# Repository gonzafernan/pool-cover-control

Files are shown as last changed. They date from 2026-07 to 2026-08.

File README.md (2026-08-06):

# Pool Cover Control Board

Electronic control board for an automatic residential pool cover. Drives a 24V DC brushed motor in both directions using a relay H-bridge, with inputs from a key switch and mechanical limit switches.

## Overview

The board replaces a failed original controller. It is designed for direct drop-in installation into the existing enclosure, preserving all external wiring and mechanical components.

## Hardware

- **MCU:** STM32G031K8T6 (ARM Cortex-M0+, 64MHz, no external crystal)
- **Motor control:** 4x SLA-24VDC-SL-C SPDT relays in H-bridge configuration, driven by ULN2003A
- **Power input:** 24V, 10A fused, from external 25A/600W PSU in the same enclosure
- **Logic supply:** 3.3V via LMR14206XMKE/NOPB synchronous buck converter
- **Inputs:** 3-position maintained key switch, two NC limit switches, isolated via PC817 optocouplers
- **Protection:** Reverse polarity (P-FET), motor TVS, relay hardware interlock, firmware watchdog
- **Manufacturer:** JLCPCB

## Firmware

- Toolchain: STM32CubeMX + Makefile + GCC
- State machine: IDLE / OPENING / CLOSING / FAULT
- Motor timeout: 60 seconds
- Internal IWDG watchdog enabled

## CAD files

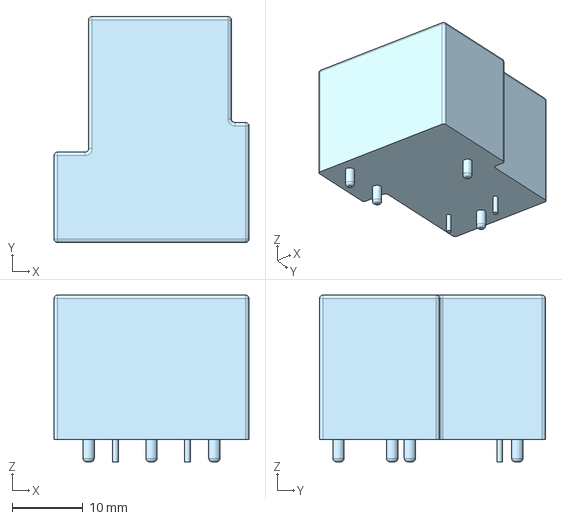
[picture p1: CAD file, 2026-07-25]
hardware/3d-models/SLA-24VDC-SL-C.step
27.6 x 32.0 x 23.6 mm

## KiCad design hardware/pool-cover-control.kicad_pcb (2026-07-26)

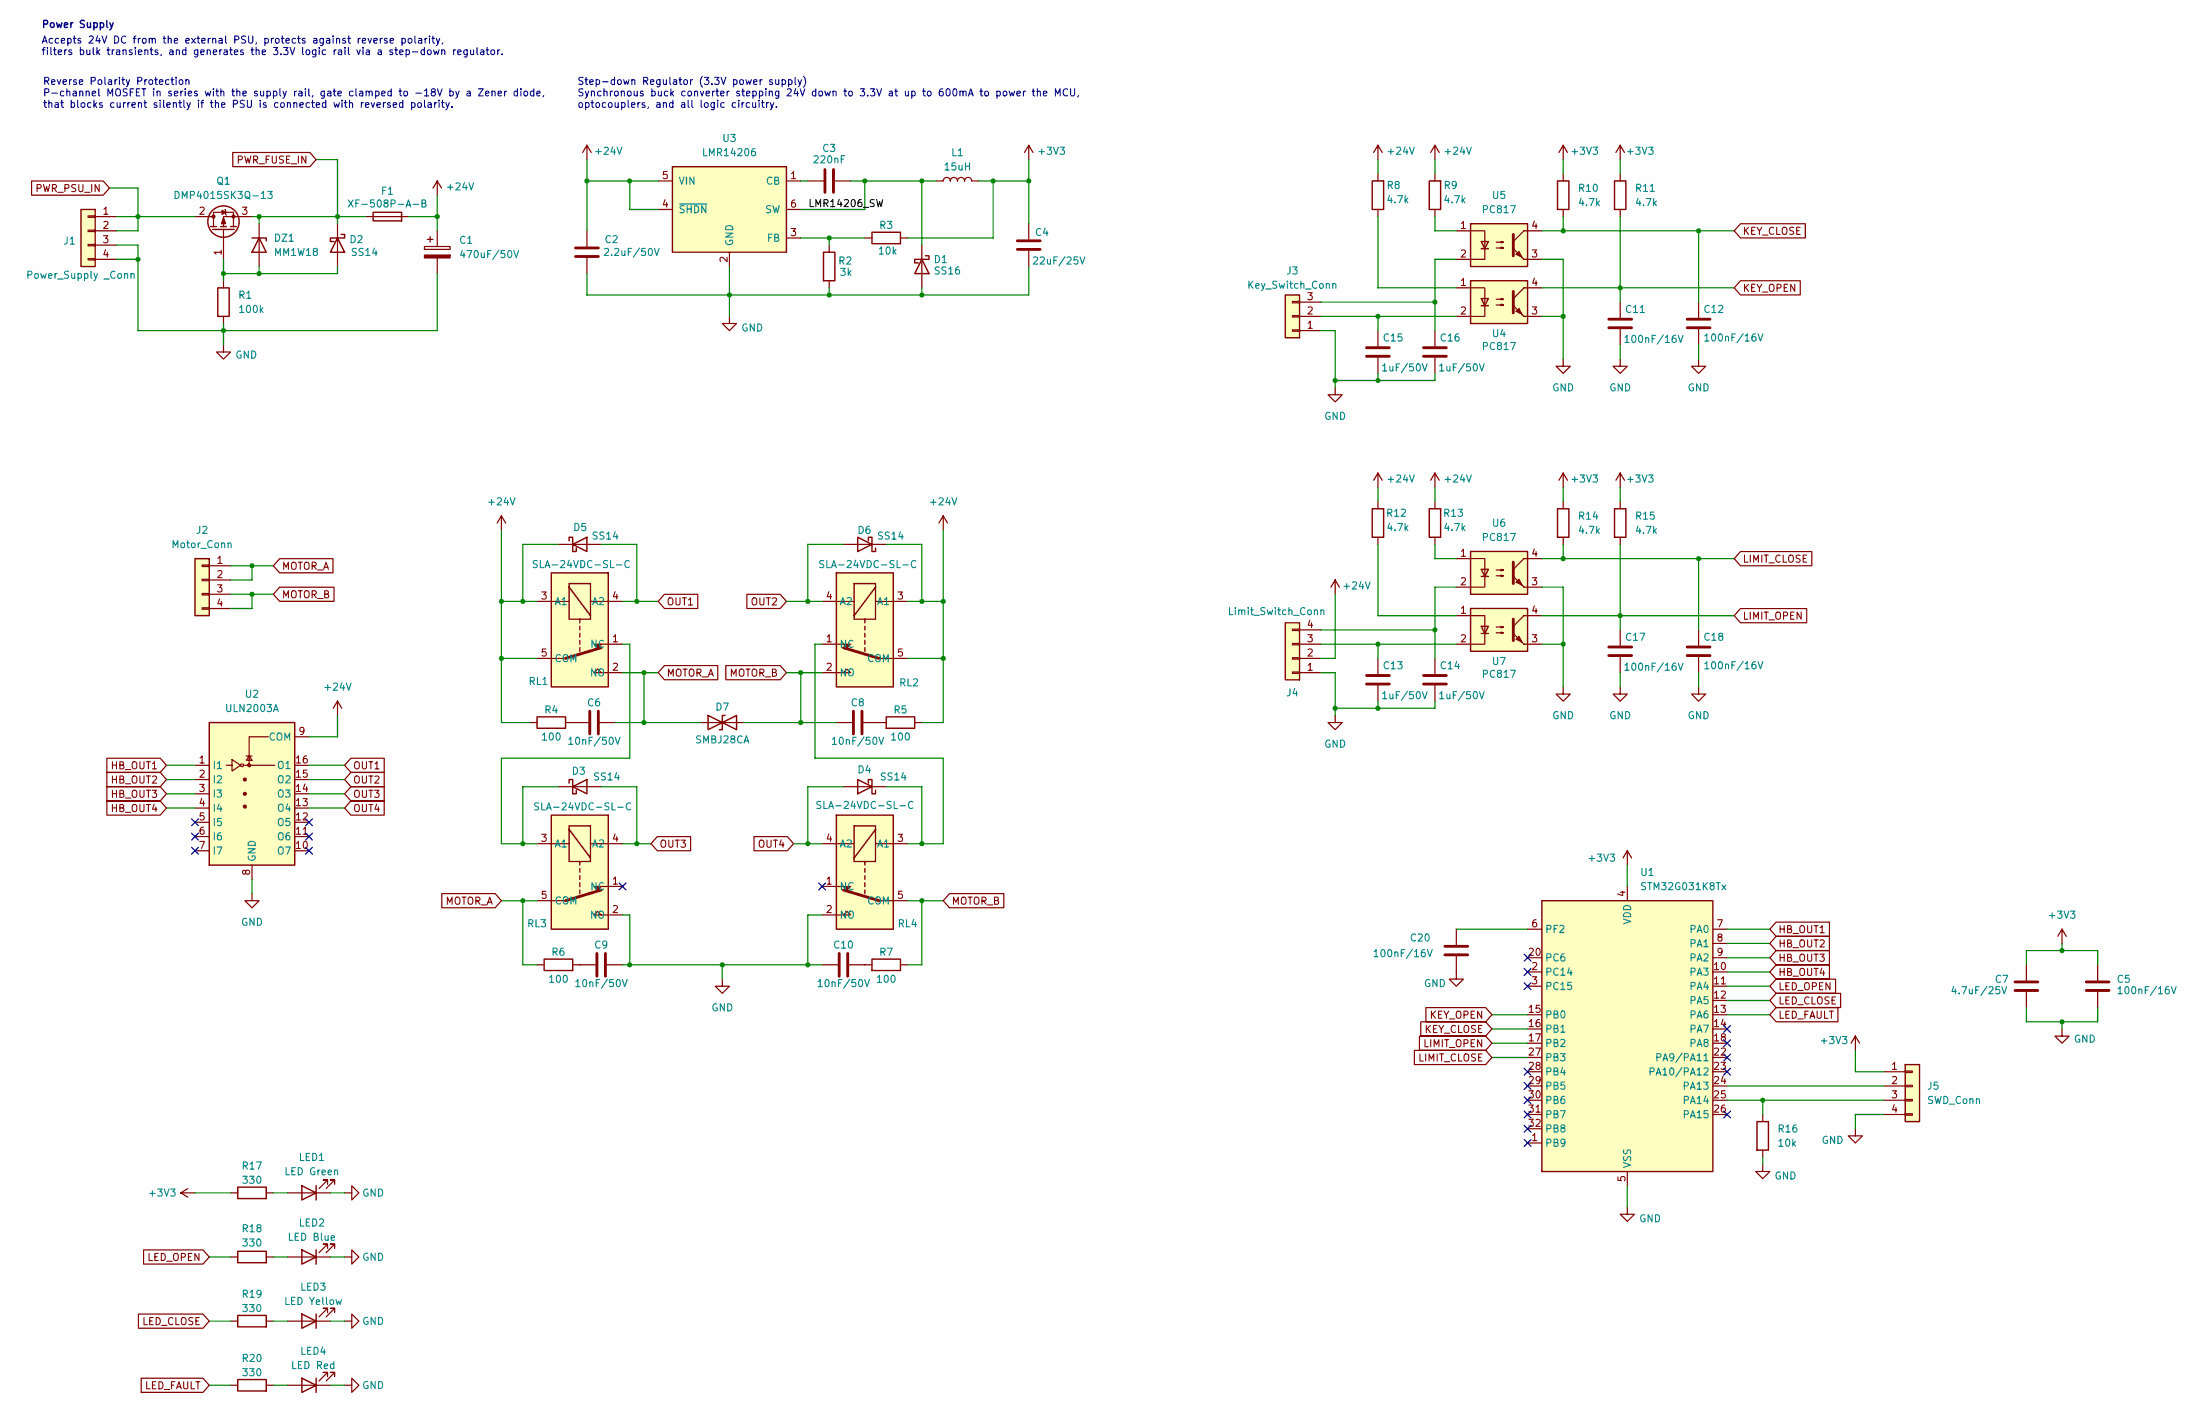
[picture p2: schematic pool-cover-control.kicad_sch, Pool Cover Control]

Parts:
C1: 470uF/50V; C_Radial_D10.0mm_H20.0mm_P5.00mm; LCSC C233099
C2: 2.2uF/50V; C_1206_3216Metric; LCSC 1206
C3: 220nF; C_0603_1608Metric; LCSC C21120
C4: 22uF/25V; C_1206_3216Metric; LCSC C12891
C5, C11, C12, C17, C18, C20: 100nF/16V; C_0402_1005Metric; LCSC C1525
C6, C8, C9, C10: 10nF/50V; C_0603_1608Metric; LCSC C57112
C7: 4.7uF/25V; C_0805_2012Metric; LCSC C1779
C13, C14, C15, C16: 1uF/50V; C_0603_1608Metric; LCSC C15849
D1: SS16; D_SMA; LCSC C908233
D2, D3, D4, D5, D6: SS14; D_SMA; LCSC C2480
D7: SMBJ28CA; D_SMB; LCSC C151259
DZ1: MM1W18; D_SOD-123; LCSC C382948
F1: XF-508P-A-B; Fuseholder_Blade_Mini_XFCN XF-508P-A-B; LCSC C19727304
J1: Power_Supply _Conn; TerminalBlock_Phoenix_MKDS-1,5-4-5.08_1x04_P5.08mm_Horizont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; LCSC C90087
J2: Motor_Conn; TerminalBlock_Phoenix_MKDS-1,5-4-5.08_1x04_P5.08mm_Horizont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; LCSC C90087
J3: Key_Switch_Conn; TerminalBlock_Phoenix_MKDS-1,5-3-5.08_1x03_P5.08mm_Horizont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; LCSC C91156
J4: Limit_Switch_Conn; TerminalBlock_Phoenix_MKDS-1,5-4-5.08_1x04_P5.08mm_Horizont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; LCSC C90087
J5: SWD_Conn; PinHeader_1x04_P2.54mm_Vertical; LCSC C2691448
L1: 15uH; L_Bourns_SRP7028A_7.3x6.6mm; LCSC C1847948
LED1: LED Green; LED_0603_1608Metric; LCSC C2286
LED2: LED Blue; LED_0603_1608Metric; LCSC C2286
LED3: LED Yellow; LED_0603_1608Metric; LCSC C2286
LED4: LED Red; LED_0603_1608Metric; LCSC C2286
Q1: DMP4015SK3Q-13; TO-252-3_TabPin2; LCSC C461089
R1: 100k; R_0402_1005Metric; LCSC C25741
R2: 3k; R_0603_1608Metric; LCSC C4211
R3, R16: 10k; R_0603_1608Metric; LCSC C25804
R4, R5, R6, R7: 100; R_0603_1608Metric; LCSC C22775
R8, R9, R12, R13: 4.7k; R_1206_3216Metric_Pad1.30x1.75mm_HandSolder; LCSC C17936
R10, R11, R14, R15: 4.7k; R_0402_1005Metric; LCSC C25900
R17, R18, R19, R20: 330; R_0402_1005Metric; LCSC C25104
RL1, RL2, RL3, RL4: SLA-24VDC-SL-C; SLA-XXVDC-SL-C; LCSC C187898
U1: STM32G031K8Tx; LQFP-32_7x7mm_P0.8mm; LCSC C724059
U2: ULN2003A; SOIC-16_3.9x9.9mm_P1.27mm; LCSC C7512
U3: LMR14206; SOT-23-6; LCSC C2071127
U4, U5, U6, U7: PC817; SOP-4_7.5x4.1mm_P2.54mm; LCSC C22447129

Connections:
+3V3: C4.2, C5.2, C7.2, J5.1, L1.2, R3.2, R10.1, R11.1, R14.1, R15.1, R17.1, U1.4 (VDD)
+24V: C1.1, C2.2, D5.1 (K), D6.1 (K), F1.2, J4.2, R4.1, R5.1, R8.2, R9.2, R12.2, R13.2, RL1.3 (A1), RL1.5 (COM), RL2.3 (A1), RL2.5 (COM), U2.9 (COM), U3.4 (~SHDN), U3.5 (VIN)
/LMR14206_SW: C3.2, D1.1 (K), L1.1, U3.6 (SW)
GND: C1.2, C2.1, C4.1, C5.1, C7.1, C9.2, C10.2, C11.1, C12.1, C13.1, C14.1, C15.1, C16.1, C17.1, C18.1, C20.1, D1.2 (A), J1.3, J1.4, J3.1, J4.1, J5.4, LED1.1 (K), LED2.1 (K), LED3.1 (K), LED4.1 (K), R1.2, R2.2, R16.2, RL3.2 (NO), RL4.2 (NO), U1.5 (VSS), U2.8 (GND), U3.2 (GND), U4.3, U5.3, U6.3, U7.3
HB_OUT1: U1.7 (PA0), U2.1 (I1)
HB_OUT2: U1.8 (PA1), U2.2 (I2)
HB_OUT3: U1.9 (PA2), U2.3 (I3)
HB_OUT4: U1.10 (PA3), U2.4 (I4)
KEY_CLOSE: C12.2, R10.2, U1.16 (PB1), U5.4
KEY_OPEN: C11.2, R11.2, U1.15 (PB0), U4.4
LED_CLOSE: R19.1, U1.12 (PA5)
LED_FAULT: R20.1, U1.13 (PA6)
LED_OPEN: R18.1, U1.11 (PA4)
LIMIT_CLOSE: C18.2, R14.2, U1.27 (PB3), U6.4
LIMIT_OPEN: C17.2, R15.2, U1.17 (PB2), U7.4
MOTOR_A: C6.2, D7.1 (A1), J2.1, J2.2, R6.1, RL1.2 (NO), RL3.5 (COM)
MOTOR_B: C8.2, D7.2 (A2), J2.3, J2.4, R7.1, RL2.2 (NO), RL4.5 (COM)
unnamed: C6.1, R4.2
unnamed: C8.1, R5.2
unnamed: C9.1, R6.2
unnamed: C10.1, R7.2
unnamed: D2.2 (A), DZ1.2 (A), Q1.1 (G), R1.1
unnamed: D3.1 (K), RL1.1 (NC), RL3.3 (A1)
unnamed: D4.1 (K), RL2.1 (NC), RL4.3 (A1)
unnamed: C15.2, J3.2, U4.2
unnamed: C16.2, J3.3, U5.2
unnamed: C13.2, J4.3, U7.2
unnamed: C14.2, J4.4, U6.2
unnamed: J5.2, U1.24 (PA13)
unnamed: J5.3, R16.1, U1.25 (PA14)
unnamed: LED1.2 (A), R17.2
unnamed: LED2.2 (A), R18.2
unnamed: LED3.2 (A), R19.2
unnamed: LED4.2 (A), R20.2
unnamed: R8.1, U4.1
unnamed: R9.1, U5.1
unnamed: R12.1, U7.1
unnamed: R13.1, U6.1
unnamed: C20.2, U1.6 (PF2)
unnamed: C3.1, U3.1 (CB)
unnamed: R2.1, R3.1, U3.3 (FB)
OUT1: D5.2 (A), RL1.4 (A2), U2.16 (O1)
OUT2: D6.2 (A), RL2.4 (A2), U2.15 (O2)
OUT3: D3.2 (A), RL3.4 (A2), U2.14 (O3)
OUT4: D4.2 (A), RL4.4 (A2), U2.13 (O4)
PWR_FUSE_IN: D2.1 (K), DZ1.1 (K), F1.1, Q1.3 (S)
PWR_PSU_IN: J1.1, J1.2, Q1.2 (D)

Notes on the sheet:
Reverse Polarity Protection P-channel MOSFET in series with the supply rail, gate clamped to −18V by a Zener diode, that blocks current silently if the PSU is connected with reversed polarity.
Power Supply
Accepts 24V DC from the external PSU, protects against reverse polarity, filters bulk transients, and generates the 3.3V logic rail via a step-down regulator.
Step-down Regulator (3.3V power supply) Synchronous buck converter stepping 24V down to 3.3V at up to 600mA to power the MCU, optocouplers, and all logic circuitry.

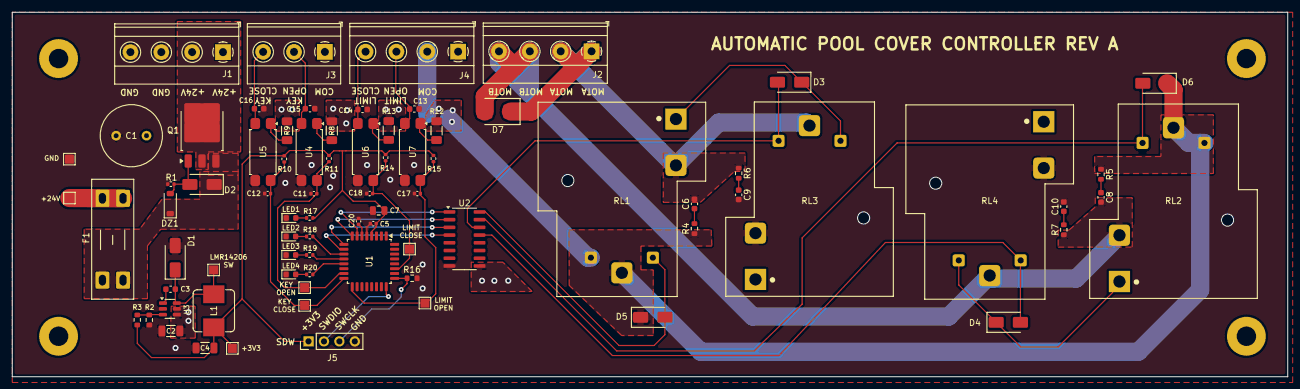
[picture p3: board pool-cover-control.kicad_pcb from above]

Board: 2 copper layers, 210.0 x 60.0 mm, 70 parts (0 on the bottom side), 47 nets.

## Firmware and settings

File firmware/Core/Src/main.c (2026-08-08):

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
/* Includes ------------------------------------------------------------------*/
#include "main.h"
#include "gpio.h"
#include "iwdg.h"

/* USER CODE BEGIN Includes */
#include "hbridge.h"
#include "key.h"
/* USER CODE END Includes */


void SystemClock_Config(void);
/**
 * @brief  The application entry point.
 * @retval int
 */
int main(void) {

  /* USER CODE BEGIN 1 */
  key_state_t key_state;
  /* USER CODE END 1 */

  /* MCU Configuration--------------------------------------------------------*/

  /* Reset of all peripherals, Initializes the Flash interface and the Systick.
   */
  HAL_Init();

  /* USER CODE BEGIN Init */
  __HAL_DBGMCU_FREEZE_IWDG();
  /* USER CODE END Init */

  /* Configure the system clock */
  SystemClock_Config();

  /* Initialize all configured peripherals */
  MX_GPIO_Init();
  MX_IWDG_Init();
  /* USER CODE BEGIN 2 */
  key_init(KEY_OPEN_GPIO_Port, KEY_OPEN_Pin, KEY_CLOSE_GPIO_Port,
           KEY_CLOSE_Pin);

  hbridge_init(HB_OUT1_GPIO_Port, HB_OUT1_Pin, HB_OUT2_GPIO_Port, HB_OUT2_Pin,
               HB_OUT3_GPIO_Port, HB_OUT3_Pin, HB_OUT4_GPIO_Port, HB_OUT4_Pin);
  /* USER CODE END 2 */

  /* Infinite loop */
  /* USER CODE BEGIN WHILE */
  while (1) {
    key_update();
    key_state = key_get_state();
    if (key_state == KEY_OPEN) {
      HAL_GPIO_WritePin(LED_OPEN_GPIO_Port, LED_OPEN_Pin, GPIO_PIN_SET);
      HAL_GPIO_WritePin(LED_CLOSE_GPIO_Port, LED_CLOSE_Pin, GPIO_PIN_RESET);
      HAL_GPIO_WritePin(LED_FAULT_GPIO_Port, LED_FAULT_Pin, GPIO_PIN_RESET);
      hbridge_set_state(HBRIDGE_POSITIVE);
    } else if (key_state == KEY_CLOSE) {
      HAL_GPIO_WritePin(LED_CLOSE_GPIO_Port, LED_CLOSE_Pin, GPIO_PIN_SET);
      HAL_GPIO_WritePin(LED_OPEN_GPIO_Port, LED_OPEN_Pin, GPIO_PIN_RESET);
      HAL_GPIO_WritePin(LED_FAULT_GPIO_Port, LED_FAULT_Pin, GPIO_PIN_RESET);
      hbridge_set_state(HBRIDGE_NEGATIVE);
    } else {
      HAL_GPIO_WritePin(LED_FAULT_GPIO_Port, LED_FAULT_Pin, GPIO_PIN_SET);
      HAL_GPIO_WritePin(LED_OPEN_GPIO_Port, LED_OPEN_Pin, GPIO_PIN_RESET);
      HAL_GPIO_WritePin(LED_CLOSE_GPIO_Port, LED_CLOSE_Pin, GPIO_PIN_RESET);
      hbridge_set_state(HBRIDGE_NONE);
    }
    HAL_IWDG_Refresh(&hiwdg);

    /* USER CODE END WHILE */

    /* USER CODE BEGIN 3 */
  }
  /* USER CODE END 3 */
}

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


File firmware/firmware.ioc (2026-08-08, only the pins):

Mcu.UserName=STM32G031K8Tx
PA0.GPIO_Label=HB_OUT1
PA0.Signal=GPIO_Output
PA1.GPIO_Label=HB_OUT2
PA1.Signal=GPIO_Output
PA13.Signal=SYS_SWDIO
PA14-BOOT0.Signal=SYS_SWCLK
PA2.GPIO_Label=HB_OUT3
PA2.Signal=GPIO_Output
PA3.GPIO_Label=HB_OUT4
PA3.Signal=GPIO_Output
PA4.GPIO_Label=LED_OPEN
PA4.Signal=GPIO_Output
PA5.GPIO_Label=LED_CLOSE
PA5.Signal=GPIO_Output
PA6.GPIO_Label=LED_FAULT
PA6.Signal=GPIO_Output
PB0.GPIO_Label=KEY_OPEN
PB0.Signal=GPIO_Input
PB1.GPIO_Label=KEY_CLOSE
PB1.Signal=GPIO_Input

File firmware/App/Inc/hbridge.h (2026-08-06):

/**
 * @file hbridge.h
 * @author Gonzalo G. Fernandez
 *
 */

#ifndef HBRIDGE_H_
#define HBRIDGE_H_

#ifdef __cplusplus
extern "C" {
#endif

#include <stdint.h>

#include "stm32g0xx_hal.h"

typedef enum {
  HBRIDGE_NONE = 0,
  HBRIDGE_POSITIVE,
  HBRIDGE_NEGATIVE,
} hbridge_state_t;

void hbridge_init(GPIO_TypeDef *out1_port, uint16_t out1_pin,
                  GPIO_TypeDef *out2_port, uint16_t out2_pin,
                  GPIO_TypeDef *out3_port, uint16_t out3_pin,
                  GPIO_TypeDef *out4_port, uint16_t out4_pin);

void hbridge_set_state(hbridge_state_t state);

#ifdef __cplusplus
}
#endif

#endif /* HBRIDGE_H_ */

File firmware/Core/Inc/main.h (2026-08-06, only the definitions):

#define HB_OUT1_Pin GPIO_PIN_0
#define HB_OUT1_GPIO_Port GPIOA
#define HB_OUT2_Pin GPIO_PIN_1
#define HB_OUT2_GPIO_Port GPIOA
#define HB_OUT3_Pin GPIO_PIN_2
#define HB_OUT3_GPIO_Port GPIOA
#define HB_OUT4_Pin GPIO_PIN_3
#define HB_OUT4_GPIO_Port GPIOA
#define LED_OPEN_Pin GPIO_PIN_4
#define LED_OPEN_GPIO_Port GPIOA
#define LED_CLOSE_Pin GPIO_PIN_5
#define LED_CLOSE_GPIO_Port GPIOA
#define LED_FAULT_Pin GPIO_PIN_6
#define LED_FAULT_GPIO_Port GPIOA
#define KEY_OPEN_Pin GPIO_PIN_0
#define KEY_OPEN_GPIO_Port GPIOB
#define KEY_CLOSE_Pin GPIO_PIN_1
#define KEY_CLOSE_GPIO_Port GPIOB

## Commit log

2026-07-25 chore(project): init KiCad project and add gitignore
    [pool-cover-control.kicad_pcb, pool-cover-control.kicad_sch]
2026-07-25 feat(hardware): add custom SLA-12VDC-SL-C symbol and footprint
    [pool-cover-control.kicad_sch]
2026-07-25 feat(hardware): implement SC1 power tree schematic
    [pool-cover-control.kicad_sch]
2026-07-25 feat(hardware): implement SC2 H-bridge schematic
    [pool-cover-control.kicad_sch]
2026-07-25 feat(hardware): implement SC3 key switch and SC4 limit switch schematic
    [pool-cover-control.kicad_sch]
2026-07-25 feat(hardware): implement SC5 mcu stm32g031 schematic
    [pool-cover-control.kicad_sch]
2026-07-25 feat(hardware): implement SC6 LEDs and SC7 power connectors schematic
    [pool-cover-control.kicad_sch]
2026-07-25 feat(hardware): review complete schematic
    [pool-cover-control.kicad_sch]
2026-07-25 feat(hardware): implement pcb layout
    [pool-cover-control.kicad_pcb, pool-cover-control.kicad_sch]
2026-07-25 fix(hardware): improve relay sla footprint and add 3d model
    [SLA-24VDC-SL-C.step, pool-cover-control.kicad_pcb]
2026-07-25 feat(hardware): add 24 vcc pin to limit switch conn for flexibility
    [pool-cover-control.kicad_pcb, pool-cover-control.kicad_sch]
2026-07-25 feat(hardware): update resistors out of stock in lcsc
    [pool-cover-control.kicad_sch]
2026-07-25 feat(hardware): add useful testpoints in layout
    [pool-cover-control.kicad_pcb, pool-cover-control.kicad_sch]
2026-07-25 feat(hardware): add custom footprint for fuse holder and optos
    [pool-cover-control.kicad_pcb, pool-cover-control.kicad_sch]
2026-07-25 fix(hardware): review for JLCPCB standard parts
    [pool-cover-control.kicad_pcb, pool-cover-control.kicad_sch]
2026-07-26 chore(hardware): ignore KiCad local history and manufacturing output
2026-07-26 feat(firmware): add STM32CubeMX project scaffold for STM32G031K8T6
2026-07-26 refactor(hardware): flatten hardware/kicad/ to hardware/
    [SLA-24VDC-SL-C.step, pool-cover-control.kicad_pcb, pool-cover-control.kicad_sch]
2026-07-26 chore(hardware): upgrade project files to KiCad 10 format
    [pool-cover-control.kicad_pcb, pool-cover-control.kicad_sch]
2026-08-06 feat(firmware): add key input driver with debounce
2026-08-06 feat(firmware): add hbridge driver and leds indication

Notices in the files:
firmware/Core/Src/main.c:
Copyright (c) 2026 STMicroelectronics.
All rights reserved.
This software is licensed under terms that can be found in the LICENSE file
